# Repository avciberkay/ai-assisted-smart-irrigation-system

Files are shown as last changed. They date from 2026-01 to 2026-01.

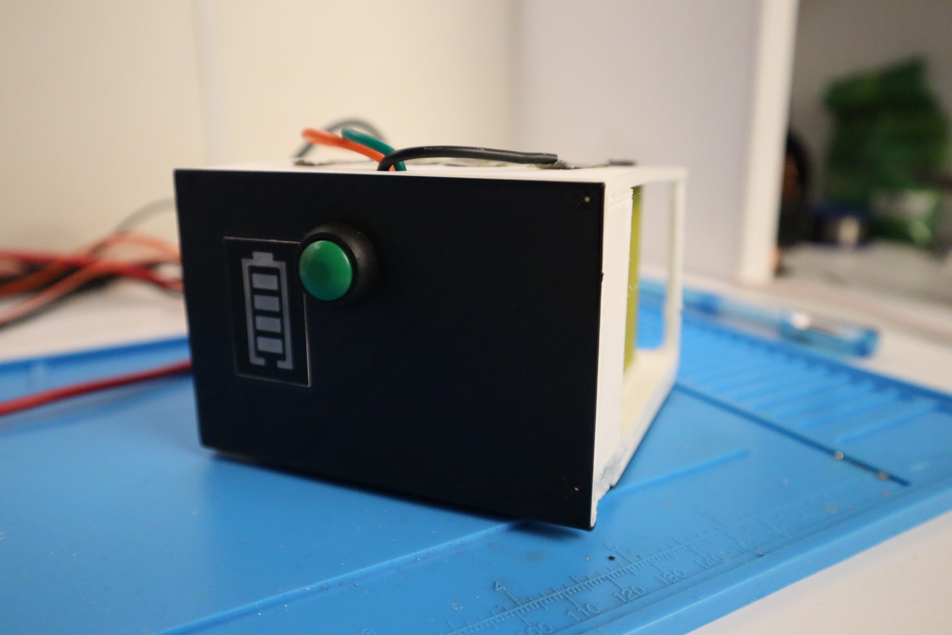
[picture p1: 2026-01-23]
media/photos/IMG_6975.jpg

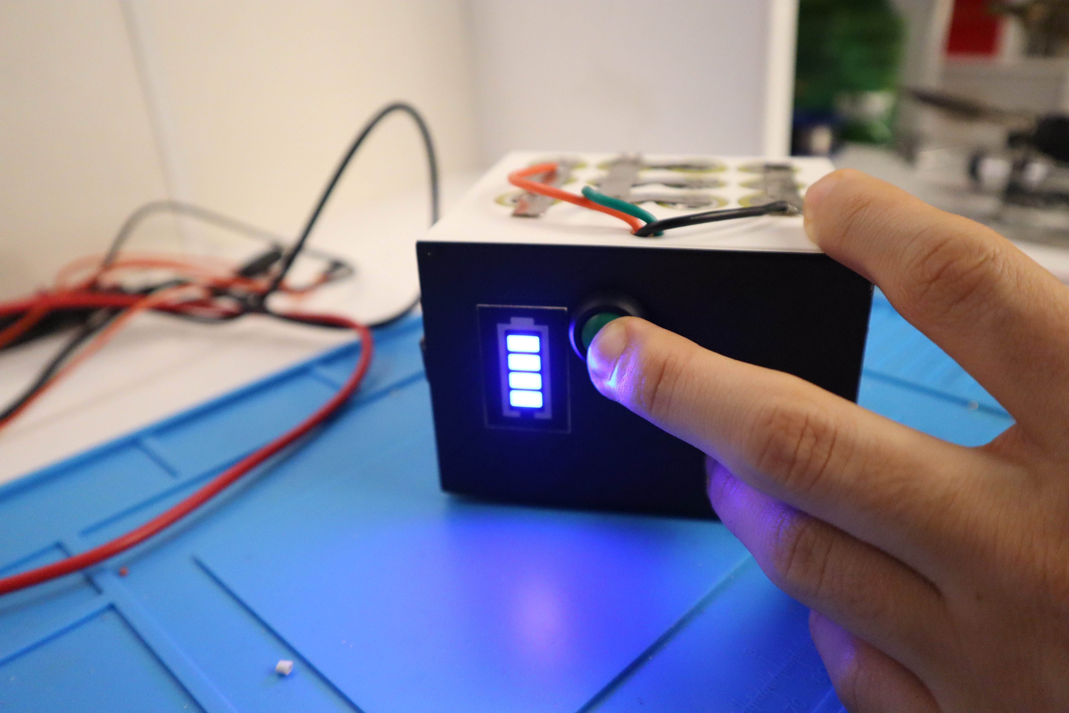
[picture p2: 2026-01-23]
media/photos/IMG_6976.jpg

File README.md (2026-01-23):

# AI Assisted Smart Irrigation System

This project is an end-to-end smart irrigation system that I designed and built to solve a real, practical problem.

Most irrigation systems are either fully manual or based on fixed threshold logic. In real environments this approach performs poorly. Soil behavior changes over time, plants have different requirements, and weather conditions continuously affect irrigation needs.

The goal of this project was to build a system that can sense the environment, understand context, and make reliable autonomous decisions without requiring human approval.

The system combines embedded hardware, power electronics, cloud infrastructure, automation workflows, external data sources, and AI-assisted decision logic into a single working system.

---

## What this system does

The system continuously measures soil and environmental conditions and transmits the data to a self-hosted backend server.

In addition to raw sensor data, the system considers:
- plant characteristics defined in the automation logic
- real-time weather data fetched through external APIs

This allows irrigation decisions to be context-aware, rather than purely reactive.

Based on all available inputs, the system decides autonomously whether irrigation is required.  
If irrigation is needed, the pump is activated for a calculated duration and the operation is logged.

Notifications are sent to the user for monitoring and transparency only, not for approval.  
Human approval was intentionally removed after long-term testing proved the system to be stable and reliable.

The system is designed to operate continuously using a multi-source power architecture.

---

## System overview

At a high level, the system consists of:

- ESP32-based embedded field node  
- Soil moisture and environmental sensors  
- Relay-controlled water pump  
- Multi-source power system (solar, grid, battery)  
- Self-hosted backend running on a VPS  
- MQTT-based communication  
- Automation workflows  
- AI-assisted decision logic  
- External weather data integration  

All components were designed and validated to operate together as a single system.

---

## Hardware layer

The hardware was designed with reliability, safety, and energy efficiency in mind.

- ESP32 is used as the main controller  
- Soil moisture is measured using capacitive sensors  
- Environmental data such as temperature and humidity are collected  
- Pump control is isolated through relay switching  

### Power system

The power system is one of the core engineering components of this project.

Instead of relying on a single source, the system integrates:
- a solar panel
- city electricity via adapter
- a custom 4S3P lithium-ion battery pack with BMS

Hardware-level source selection, CCCV charging, diode OR-ing, and fuse protection are used to ensure:
- safe charging
- no back-feeding
- uninterrupted operation during power loss

Detailed power design notes and validation results are documented in the `hardware/` directory.

### Enclosure and wiring

The system was built as a functional prototype using direct wiring rather than a full system PCB, allowing rapid iteration and debugging.

A dedicated 3D-designed battery enclosure is included to demonstrate mechanical design capability and battery safety considerations.

---

## Firmware layer (ESP32)

The ESP32 firmware is responsible for:

- sensor sampling and timing  
- preprocessing of raw ADC values  
- MQTT communication with the backend  
- receiving irrigation commands  
- controlling pump activation safely  

Soil moisture sensors return raw ADC values in the range 0–4095, where lower values indicate wetter soil.

Decision making is intentionally kept out of the firmware.  
The ESP32 focuses on deterministic, reliable execution and safe operation.

Firmware source code is available in the `firmware/` directory.

---

## Backend and automation layer

The backend is fully self-hosted on a VPS.

- Docker is used to containerize services  
- Mosquitto handles MQTT communication  
- Nginx acts as a reverse proxy  
- Automation workflows are built using n8n  

Incoming sensor data is processed together with external weather data and plant-specific parameters.

Irrigation decisions are produced automatically and executed without manual intervention.  
All services are containerized and reproducible using documented configurations.

Backend architecture and deployment notes are available in the `backend/` and `deployment/` directories.

---

## AI integration

AI is used as a decision interpretation layer, not as a direct hardware controller.

The AI component:
- evaluates sensor readings together with weather context  
- produces structured irrigation decisions  
- generates human-readable explanations for logs and notifications  

Final control actions are executed through deterministic automation logic, ensuring system stability and predictability.

---

## Testing and validation

The system was tested continuously under real operating conditions.

- Battery voltage remained stable  
- No abnormal thermal behavior was observed  
- Power consumption was low  
- Water usage was consistent and controlled  

The system operated autonomously for extended periods without human approval.  
This was a real deployment, not a simulation.

---

## Project video and public links

Project demonstration video:  
https://www.youtube.com/watch?v=rDrQLltPG3M

LinkedIn:  
https://www.linkedin.com/in/berkay-avci-istanbul

---

## Academic evaluation

This project received an AA grade.

The technical report was reviewed positively and appreciated for its system-level design, documentation quality, and practical validation.

---

## Repository structure

- `hardware/` – power system, wiring, enclosure, and mechanical design  
- `firmware/` – ESP32 source code  
- `backend/` – Docker, MQTT, automation, and service architecture  
- `deployment/` – VPS and security notes  
- `docs/` – system diagrams and architecture documentation  
- `media/` – photos, diagrams, and video links  

---

## Future improvements

- Web-based monitoring dashboard  
- Long-term field calibration  
- Multi-node deployment  
- Advanced fault detection  
- Expanded plant database  
- Predictive irrigation strategies  

---

## Final note

This project reflects how I approach engineering problems.

I focus on complete systems, real constraints, and real validation rather than isolated components or simulations.

Every part of this repository represents a working or documented component of the final system.

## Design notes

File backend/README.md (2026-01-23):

## Backend Overview

This backend runs on a self-hosted VPS and supports the smart irrigation system.

It receives sensor data from ESP32 devices via MQTT, processes the data, applies automation logic, and sends notifications.

The backend services are containerized using Docker.
A sanitized reference configuration is provided for reproducibility.

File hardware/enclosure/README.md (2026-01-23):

## Enclosure

The system components are housed inside a protective enclosure suitable for outdoor use.

The enclosure was selected to:
- Protect electronics from dust and moisture
- Allow safe cable entry and exit
- Support mounting of power components and controller
- Enable maintenance access when required

Cable glands and sealed openings are used to prevent water ingress.
Internal spacing was arranged to separate power electronics from low-voltage logic components.

The enclosure design prioritizes functionality and protection rather than aesthetics, with plans to optimize layout in a future PCB-based revision.

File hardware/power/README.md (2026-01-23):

## Power System Overview

The power subsystem is a core component of the smart irrigation system and is designed for autonomous, long-term operation.

The system does not rely on a single power source. Instead, it integrates multiple energy inputs and manages them at the hardware level without human intervention.

Primary characteristics:
- Multi-source power input architecture
- Automatic source selection and prioritization
- Battery charging and protection handled in hardware
- Stable power delivery to both logic and motor loads

The power system was designed to keep the system operational under changing environmental and grid conditions and to minimize maintenance requirements in real-world deployments.

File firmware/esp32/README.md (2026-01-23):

## ESP32 Firmware

This folder contains the firmware that runs on the ESP32 field unit.

The ESP32 is responsible for:
- Reading soil moisture sensors (raw ADC values)
- Formatting sensor readings into a message payload
- Publishing sensor data to the backend via MQTT
- Subscribing to irrigation control commands via MQTT
- Activating the irrigation pump for the commanded duration

### Sensor Logic

Soil moisture sensors are read as RAW ADC values in the range 0 to 4095.
Lower values represent wetter soil and higher values represent drier soil.

### Communication

Sensor data is published to an MQTT topic used by the backend automation workflow.
The pump duration command is received from another MQTT topic and executed locally.

### Notes

This firmware is designed to keep device-side logic minimal.
Decision making is handled on the backend by combining sensor readings with weather data and AI-based evaluation.

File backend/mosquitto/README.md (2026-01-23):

## Mosquitto Broker

Mosquitto is used as the MQTT broker implementation in this system.

It handles message exchange between ESP32 devices and backend services.
The broker listens on standard MQTT ports and supports both unencrypted and encrypted connections.

Mosquitto runs as a Docker container.
Configuration files are mounted into the container to define listeners, persistence, and security options.

Only a sanitized reference configuration is shared in this repository.

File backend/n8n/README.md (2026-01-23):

## Automation Workflows (n8n)

The system uses n8n as an automation engine to process incoming sensor data and make irrigation decisions.

Workflows consume MQTT messages, combine sensor readings with external weather data, and determine whether irrigation is required.

n8n runs as a Docker container on the VPS.
Workflow logic is designed to be modular and extensible.

Production workflows are not exported directly.
This repository documents the role and structure of the automation layer.

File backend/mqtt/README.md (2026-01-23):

## MQTT Broker

The system uses an MQTT broker for communication between ESP32 devices and the backend.

Devices publish sensor data to predefined topics.
Backend automation workflows subscribe to these topics and process incoming messages.

The broker runs as a Docker container.
A reference Docker Compose

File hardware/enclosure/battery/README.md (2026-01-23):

## Battery Enclosure (3D Model)

This enclosure is designed specifically to house the 4S3P lithium-ion battery pack used in the system.

The goal of this model is to demonstrate practical 3D design skills for embedded power systems, with focus on safety, fit, and printability rather than mass production.

Design considerations:
- Secure placement of cylindrical cells to prevent movement
- Internal spacing to reduce heat buildup
- Dedicated exit path for power cables
- Simple geometry suitable for FDM 3D printing
- No assumptions about IP rating or industrial certification

This enclosure represents a functional prototype design.
It is intended to show mechanical design capability and understanding of battery safety constraints.

### Preview

A rendered preview of the battery enclosure is available in the `screenshots/` directory.

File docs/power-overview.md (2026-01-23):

## Power Overview

The system uses a multi-source, autonomous power architecture designed for continuous operation under varying environmental and grid conditions.

Instead of relying on a single energy source, the system integrates three independent power inputs:
- A high-voltage solar panel
- A city electricity adapter
- A custom-built 4S3P lithium-ion battery pack

A dedicated power distribution and selection board evaluates source availability and automatically routes the most suitable energy source to the system. When solar energy is available, it is prioritized to power the system and charge the battery. During nighttime, city electricity is preferred due to lower cost. In the event of grid failure, the system seamlessly switches to battery power without interrupting operation.

Key design goals of the power system:
- Autonomous source selection without human intervention
- Battery charging and protection handled at hardware level
- Stable voltage delivery to digital and motor loads
- Protection against over-current, reverse polarity, and voltage instability
- Support for long-term unattended outdoor operation

This architecture allows the system to remain operational across power outages, changing weather conditions, and remote deployment scenarios, while significantly reducing energy waste and manual maintenance requirements.

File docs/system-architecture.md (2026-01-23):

## System Architecture

This project is an AI-assisted smart irrigation system designed as a distributed embedded and cloud-based system.

The system consists of four main layers:

1. Field Layer  
ESP32-based embedded devices collect soil moisture sensor data and control the irrigation pump.

2. Communication Layer  
Devices communicate with the backend using the MQTT protocol over a network connection.

3. Backend Layer  
A containerized backend running on a VPS receives sensor data, processes it, fetches external weather information, and executes automation logic.

4. Decision and Notification Layer  
An AI-based decision engine evaluates sensor and weather data to determine irrigation duration.
System decisions and status updates are sent to the user via notifications.

The architecture is modular and allows individual components to be modified or scaled independently.

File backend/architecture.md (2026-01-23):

## Backend Architecture

The backend is designed as a lightweight, containerized system running on a VPS.

ESP32 devices publish sensor data to an MQTT broker.
This data is consumed by automation workflows that evaluate irrigation conditions.

External weather data is fetched via APIs and combined with sensor data.
Based on the evaluation, irrigation actions are triggered automatically and system events are logged.

The backend is structured to be reproducible and modular using Docker.

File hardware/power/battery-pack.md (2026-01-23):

## Battery Pack Design

The system uses a custom-built lithium-ion battery pack designed to support uninterrupted operation during power outages and low solar availability.

### Configuration

The battery pack is configured as a 4S3P arrangement:
- 4 cells in series to increase system voltage
- 3 cells in parallel per series group to increase capacity

This configuration provides a balance between voltage stability, current capability, and energy density suitable for both logic circuits and motor loads.

### Protection and Management

A dedicated Battery Management System (BMS) is integrated with the pack to provide:
- Over-charge protection
- Over-discharge protection
- Over-current protection
- Cell balancing

These protections ensure safe operation and extend battery lifespan under continuous outdoor use.

### Charging Strategy

Charging is handled externally by a CCCV buck converter and controlled at the hardware level.
The battery is charged only when a suitable external source is available, and reverse current flow into the charger is prevented by diode isolation.

### Real-World Validation

The battery pack was tested under real operating conditions.
During testing, the system continued operating for multiple days solely on battery power without voltage instability or unexpected shutdowns.

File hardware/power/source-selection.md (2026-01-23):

## Source Selection and Charging Logic

The power system was designed with an energy redundancy mindset. The goal is that the system keeps running even if the solar input drops or if city electricity is cut. :contentReference[oaicite:0]{index=0}

### Stage 1 Energy Selector and Charging Unit

This stage is the main energy hub where three sources meet:
- Solar panel
- AC grid adapter
- Custom 4S3P battery pack :contentReference[oaicite:1]{index=1}

A CCCV buck converter module (XL4015) is used in the charging path and tuned to safely charge the battery without overshooting voltage limits. :contentReference[oaicite:2]{index=2}

### OR-ing Logic With Schottky Diodes

Multiple power sources cannot be tied together directly because they would fight each other and cause dangerous back-feeding, such as current flowing into the solar panel or the grid adapter. :contentReference[oaicite:3]{index=3}

To prevent this and make selection automatic, the system uses OR-ing logic implemented with multiple Schottky diodes. The diode network forces the system to naturally pick the highest available voltage source while blocking reverse current flow. :contentReference[oaicite:4]{index=4}

Schottky diodes were selected specifically because of their low forward voltage drop, which improves overall energy efficiency. :contentReference[oaicite:5]{index=5}

### Field Safety With Fuses

To make the power system field-safe, fuses are integrated into key paths:
- 2.5A fuse for logic, sensors, and battery protection
- 7.5A fuse on the city electricity and charging path
- 10A fuse as a master protection for the main bus and solar input :contentReference[oaicite:6]{index=6}

### Validated Behavior in Real Tests

The selection logic was validated through stress testing by manually disconnecting sources. When the solar panel was removed, the system transitioned to AC grid power without reboot or data loss. When grid power was also removed, the system continued running on the 4S3P battery pack for an entire week. :contentReference[oaicite:7]{index=7}

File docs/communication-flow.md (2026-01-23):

## Communication Flow

The system follows a unidirectional data flow from sensors to decision logic and back to actuators.

1. ESP32 devices read soil moisture sensor values at defined intervals.
2. Sensor data is published to the backend using MQTT topics.
3. The backend subscribes to these topics and receives incoming data.
4. Weather data is fetched from an external API.
5. An AI-based automation workflow evaluates sensor and weather data together.
6. A decision is produced indicating whether irrigation is required and for how long.
7. The irrigation command is sent back to the ESP32 via MQTT.
8. A notification is sent to the user describing the decision and system status.

This flow allows real-time control while keeping device-side logic minimal.

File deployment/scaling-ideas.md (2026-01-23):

## Scaling Ideas

The current system is designed for a small number of devices and a single deployment.

Potential scaling improvements:
- Support multiple irrigation zones and device groups.
- Introduce a database for long-term sensor data storage and analytics.
- Use message queues to handle higher data throughput.
- Deploy services across multiple containers or servers.
- Add monitoring and alerting for system health.

These ideas outline possible future extensions and are not part of the current implementation.

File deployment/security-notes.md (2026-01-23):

## Security Notes

Security is considered at both the device and backend levels.

Key measures:
- Backend services run inside Docker containers to reduce attack surface.
- Sensitive credentials and API keys are not stored in the public repository.
- MQTT communication can be secured using authentication and TLS.
- Reverse proxy handles HTTPS termination.
- Firewall rules restrict access to required ports only.

All configuration files shared in this repository are sanitized examples.
Production secrets and certificates are intentionally excluded.

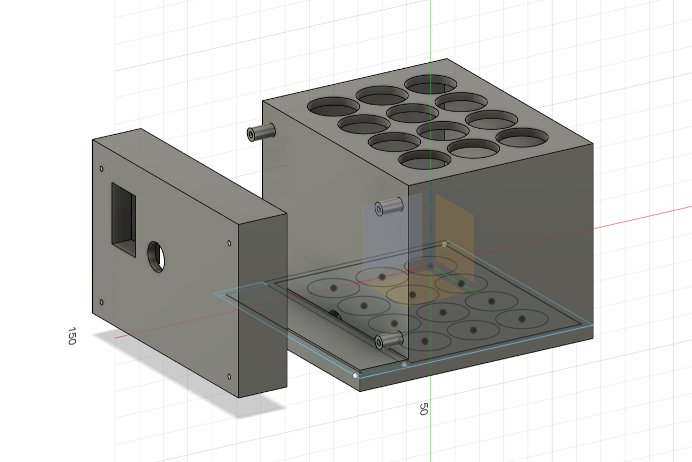
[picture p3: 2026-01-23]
hardware/enclosure/battery/screenshots/overview_1.png

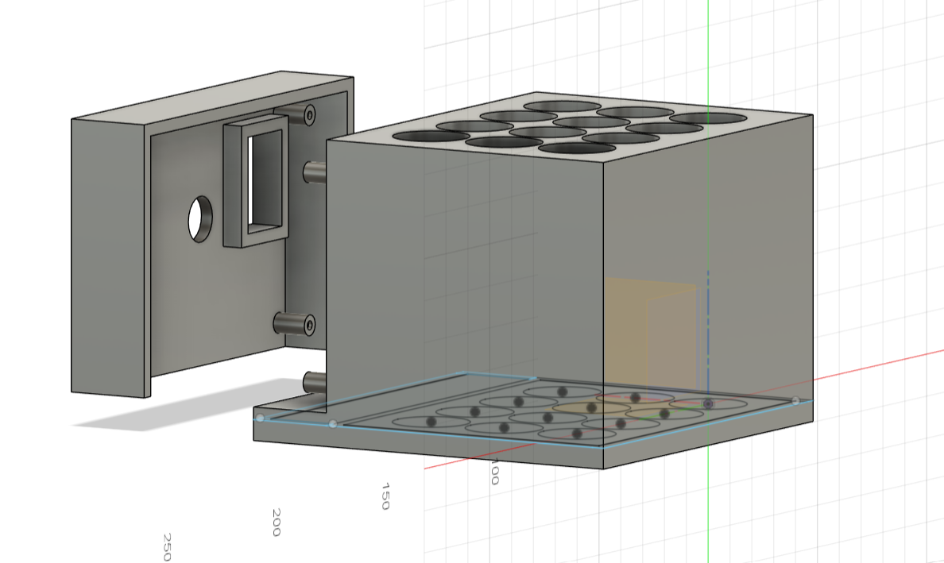
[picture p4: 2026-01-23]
hardware/enclosure/battery/screenshots/overview_2.png

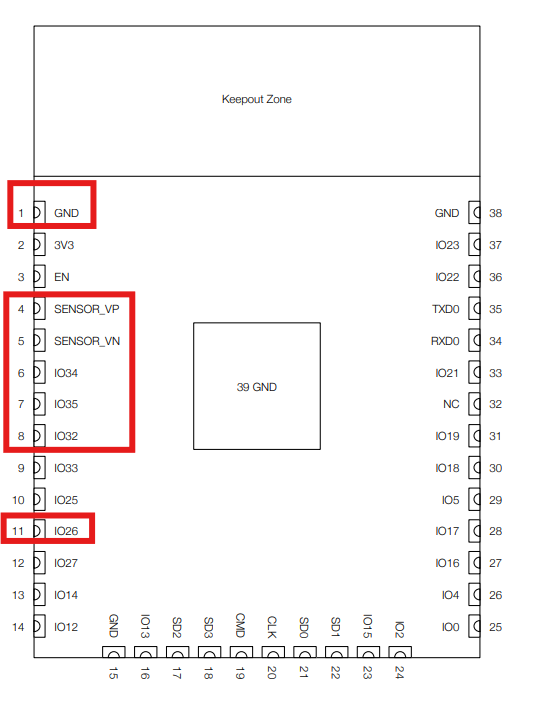
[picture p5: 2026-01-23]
media/diagrams/Picture3.png

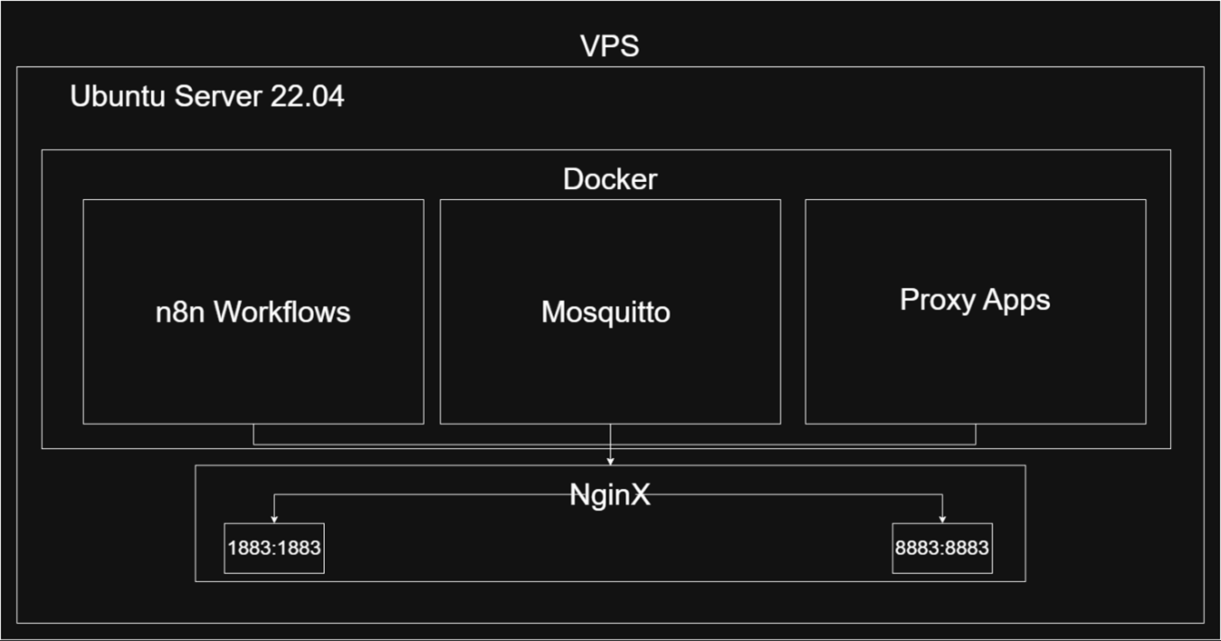
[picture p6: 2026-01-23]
media/diagrams/Picture8.png

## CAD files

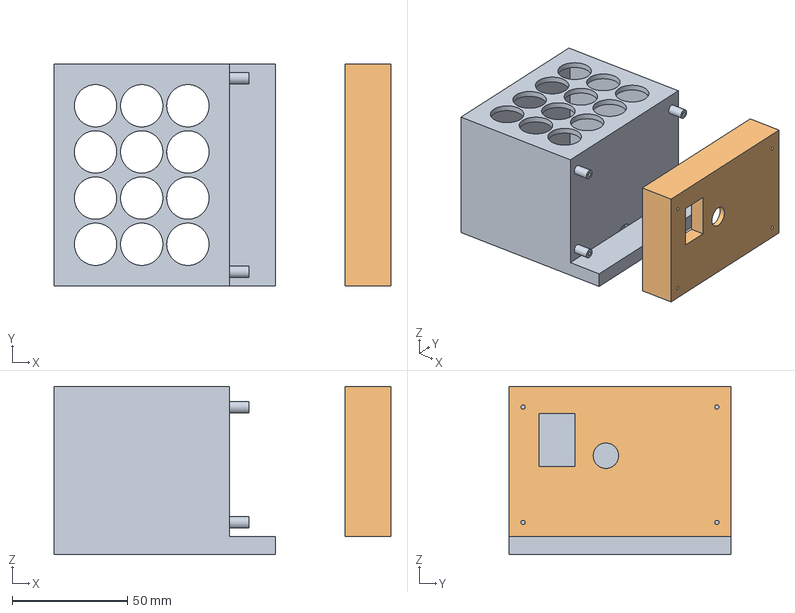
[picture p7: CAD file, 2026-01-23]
hardware/enclosure/battery/battery_enclosure.step
146.0 x 96.0 x 73.0 mm

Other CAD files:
hardware/enclosure/battery/Battery_enclosure.3mf
hardware/enclosure/battery/battery_enclosure.stl

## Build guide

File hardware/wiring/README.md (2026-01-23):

## Wiring Overview

The system was built as a functional prototype using direct wiring instead of a custom PCB.

All power and signal connections were made manually to allow rapid iteration and testing.
This approach enabled flexible debugging and hardware changes during development.

Wiring considerations:
- Separate power and signal paths to reduce noise
- Secure connections for outdoor operation
- Clear routing between sensors, controller, and actuators
- Protection against accidental short circuits

While a custom PCB is planned as a future iteration, the current wiring layout proved reliable during long-term testing and real-world operation.

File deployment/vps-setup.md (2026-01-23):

## VPS Setup

The backend runs on a Linux-based Virtual Private Server.

The server is used to host all backend services required by the smart irrigation system.
Docker and Docker Compose are installed to ensure a reproducible and isolated environment.

High-level setup steps:
1. Provision a Linux VPS.
2. Install Docker and Docker Compose.
3. Configure firewall rules to allow only required ports.
4. Deploy backend services using Docker Compose.
5. Verify service health and connectivity.

This document intentionally omits provider-specific commands and credentials.
It describes the setup conceptually to allow replication on any VPS provider.

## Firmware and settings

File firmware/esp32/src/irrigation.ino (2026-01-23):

#include <WiFi.h>
#include <WiFiClientSecure.h>
#include <PubSubClient.h>

// --- AYARLAR (Kendi Bilgilerin) ---
const char* ssid = "Your_SSID";
const char* password = "Your_Password";
const char* mqtt_server = "Your_Domain";
const char* mqtt_user = "USER";
const char* mqtt_pass = "PASSWORD";

// --- PİN TANIMLARI ---
const int pumpPin = 26;
const int sensorPins[] = {36, 39, 34, 35, 32};
const int numSensors = 5;

// --- DEĞİŞKENLER ---
bool isWatering = false;
unsigned long lastPumpOffTime = 0;
const unsigned long stabilizationDelay = 10000; 

// --- SSL SERTİFİKASI ---
const char* root_ca = "Your_Certificate"
WiFiClientSecure espClient;
PubSubClient client(espClient);

void setup_wifi() {
  Serial.print("\nConnecting to WiFi: ");
  WiFi.begin(ssid, password);
  while (WiFi.status() != WL_CONNECTED) {
    delay(500); Serial.print(".");
  }
  Serial.println("\nWiFi Connected!");
}

// --- KOMUT GELDIĞİNDE ÇALIŞAN KISIM ---
void callback(char* topic, byte* payload, unsigned int length) {
  String msg = "";
  for (int i = 0; i < length; i++) msg += (char)payload[i];
  
  // Gelen dakikayı float olarak alıyoruz
  float duration = msg.toFloat(); 
  
  if (duration > 0 && duration < 1440.0) { // Güvenlik sınırı: 24 saat
    isWatering = true;
    
    // Seri monitörde ondalıklı göstermek için %.2f kullanıyoruz
    Serial.printf("AI Decision: Watering for %.2f minutes...\n", duration);
    
    digitalWrite(pumpPin, HIGH);

    // TAŞMAYI ÖNLEYEN HESAPLAMA:
    // (Dakika * 60 saniye * 1000 milisaniye)
    // 60000.0 (noktalı) yazarak matematiksel taşmayı engelliyoruz.
    unsigned long waitTime = (unsigned long)(duration * 60000.0);
    
    delay(waitTime); 
    
    digitalWrite(pumpPin, LOW);
    isWatering = false;
    lastPumpOffTime = millis();
    Serial.println("Irrigation finished. Waiting for stabilization (10s)...");
    client.publish("irrigation/status", "completed");
  } else {
    Serial.printf("Invalid duration: %.2f\n", duration);
  }
}

void reconnect() {
  while (!client.connected()) {
    Serial.print("Connecting to MQTT...");
    if (client.connect("ESP32_Irrigation_System", mqtt_user, mqtt_pass)) {
      Serial.println("Connected!");
      client.subscribe("irrigation/pump");
    } else {
      Serial.printf("Failed, rc=%d. Retrying in 5s...\n", client.state());
      delay(5000);
    }
  }
}

void setup() {
  Serial.begin(115200);
  analogSetAttenuation(ADC_11db);
  pinMode(pumpPin, OUTPUT);
  digitalWrite(pumpPin, LOW);

  setup_wifi();
  espClient.setCACert(root_ca);
  client.setServer(mqtt_server, 8883);
  client.setCallback(callback);
}

void loop() {
  if (!client.connected()) reconnect();
  client.loop();

  static unsigned long lastMsg = 0;
  unsigned long now = millis();

  // 60 saniyede bir veri gönder (Gemini kotasını korumak için idealdir)
  if (now - lastMsg > 60000) { 
    if (!isWatering && (now - lastPumpOffTime > stabilizationDelay)) {
      lastMsg = now;
      String jsonPayload = "{";
      for(int i=0; i<numSensors; i++) {
        jsonPayload += "\"s" + String(i+1) + "\":" + String(analogRead(sensorPins[i]));
        if(i < numSensors-1) jsonPayload += ",";
      }
      jsonPayload += "}";
      client.publish("irrigation/data", jsonPayload.c_str());
      Serial.println("Data Sent: " + jsonPayload);
    }
  }
}
